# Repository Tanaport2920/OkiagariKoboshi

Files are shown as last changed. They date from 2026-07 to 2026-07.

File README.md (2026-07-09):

# Okiagari Koboshi Robot: Isaac Lab RL + M5Stack ATOM Matrix Deployment

2自由度サーボを持つ起き上がり小法師型ロボットを、Isaac Lab上でシミュレーション・強化学習し、最終的にM5Stack ATOM Matrixへ制御ポリシーを組み込むための開発メモです。

Real

Simulation

---

## 1. 目的

本プロジェクトの目的は、2軸サーボロボットを倒れた姿勢から自律的に起き上がらせることです。

開発方針は以下です。

```text
1. CAD / URDF / USD でロボットモデルを作成
2. Isaac Labで物理シミュレーション
3. 手動reference軌道で起き上がり動作を作成
4. referenceを教師軌道としてpolicyを学習
5. 学習済みActorをM5Stack ATOM Matrixへ組み込み
6. STS3032サーボを実機制御
```

---

## 3. 使用環境

### 3.1 シミュレーション環境

```text
OS:
  Ubuntu 24.04

GPU:
  NVIDIA GPU

NVIDIA Driver:
  Isaac Sim / Isaac Labに対応したNVIDIA Driver

Isaac Sim:
  Isaac Sim 5.1.0

Isaac Lab:
  Isaac Lab 2.3系

作業ディレクトリ:
  /workspace/isaaclab
  /workspace/OkiagariKoboshi_ws
```

### 3.2 実機環境

```text
Controller:
  M5Stack ATOM Matrix

MCU:
  ESP32-PICO-D4

IMU:
  MPU6886

Servo:
  FEETECH STS3032 x2

Development:
  PlatformIO
  Arduino framework
```

---

## 4. ディレクトリ構成

推奨構成は以下です。

```text
/workspace/OkiagariKoboshi_ws/
  assets/
    usd/
      okiagarikoboshi.usd
    urdf/
      okiagarikoboshi.urdf
    meshes/

  source/
    okiagari_koboshi_ext/
      pyproject.toml
      okiagari_koboshi_ext/
        __init__.py
        tasks/
          __init__.py
          direct/
            __init__.py
            okiagari_getup/
              __init__.py
              okiagari_getup_env.py
              agents/
                __init__.py
                rsl_rl_ppo_cfg.py
              references/
                __init__.py
                getup_reference.py

  tools/
    export_policy_to_c.py
```

---

## 5. Isaac Lab環境構築

Docker Composeを使う場合、ホスト側の作業ディレクトリは環境変数で渡します。

```bash
cd /path/to/OkiagariKoboshi_ws

OKIAGARI_WS_HOST=/path/to/OkiagariKoboshi_ws \
docker compose -f docker/compose.isaaclab.yml up
```

### 5.1 Isaac Labディレクトリへ移動

Isaac Labの実行は基本的に以下のディレクトリで行います。

```bash
cd /workspace/isaaclab
```

`isaaclab.sh` は `/workspace/isaaclab` にあります。
`/workspace/OkiagariKoboshi_ws` で以下を実行すると失敗します。

```bash
./isaaclab.sh
```

その場合は、必ず以下のように実行します。

```bash
cd /workspace/isaaclab
./isaaclab.sh ...
```

または絶対パスを使います。

```bash
/workspace/isaaclab/isaaclab.sh ...
```

---

## 6. Isaac Lab拡張パッケージのインストール

自作環境 `okiagari_koboshi_ext` をeditable installします。

```bash
cd /workspace/isaaclab

./isaaclab.sh -p -m pip install -e /workspace/OkiagariKoboshi_ws/source/okiagari_koboshi_ext
```

正常に入ると以下のようになります。

```text
Successfully installed okiagari-koboshi-ext-0.1.0
```

コードを変更した後は、念のため再度実行します。

```bash
cd /workspace/isaaclab

./isaaclab.sh -p -m pip install -e /workspace/OkiagariKoboshi_ws/source/okiagari_koboshi_ext
```

---

## 7. URDF / USD

ロボットのUSDファイルは以下を使用します。

```text
/workspace/OkiagariKoboshi_ws/assets/usd/okiagarikoboshi.usd
```

環境コード内では以下のように指定します。

```python
OKIAGARI_USD = "/workspace/OkiagariKoboshi_ws/assets/usd/okiagarikoboshi.usd"
```

関節名は以下です。

```text
revolute1
revolute2
```

body名は以下です。

```text
root
sts3032_horn_1
sts3032_horn
```

---

## 8. WebRTC表示

### 8.1 ロボット表示確認

WebRTCでIsaac Sim画面を表示する場合は以下を使います。

```bash
cd /workspace/isaaclab

PUBLIC_IP=YOUR_PUBLIC_IP \
LIVESTREAM=2 \
ENABLE_CAMERAS=1 \
./isaaclab.sh -p /workspace/OkiagariKoboshi_ws/isaac/scripts/spawn_robot.py \
  --kit_args "--/app/livestream/publicEndpointAddress=YOUR_PUBLIC_IP --/app/livestream/port=49100"
```

WebRTC Client側では以下へ接続します。

```text
YOUR_PUBLIC_IP
```

---

## 9. 学習中にGUIを映す

学習中にGUIを表示する場合は、`--headless` を付けません。

確認用は `num_envs` を少なくします。

```bash
cd /workspace/isaaclab

PUBLIC_IP=YOUR_PUBLIC_IP \
LIVESTREAM=2 \
ENABLE_CAMERAS=1 \
./isaaclab.sh -p scripts/reinforcement_learning/rsl_rl/train.py \
  --task OkiagariKoboshi-Getup-Direct-v0 \
  --num_envs 16 \
  --max_iterations 500 \
  --kit_args "--/app/livestream/publicEndpointAddress=YOUR_PUBLIC_IP --/app/livestream/port=49100"
```

本学習はheadless推奨です。

```bash
cd /workspace/isaaclab

./isaaclab.sh -p scripts/reinforcement_learning/rsl_rl/train.py \
  --task OkiagariKoboshi-Getup-Direct-v0 \
  --num_envs 512 \
  --headless \
  --max_iterations 1500
```

---

## 10. play.pyでの再生

RSL-RLの `play.py` では `--use_last_checkpoint` は使いません。
`--checkpoint` を指定します。

```bash
cd /workspace/isaaclab

CKPT=$(find logs/rsl_rl/okiagari_getup_v2 -type f -name "model_*.pt" | sort -V | tail -n 1)

PUBLIC_IP=YOUR_PUBLIC_IP \
LIVESTREAM=2 \
ENABLE_CAMERAS=1 \
./isaaclab.sh -p scripts/reinforcement_learning/rsl_rl/play.py \
  --task OkiagariKoboshi-Getup-Direct-v0 \
  --num_envs 16 \
  --checkpoint "$CKPT" \
  --kit_args "--/app/livestream/publicEndpointAddress=YOUR_PUBLIC_IP --/app/livestream/port=49100"
```

---

## 11. 観測設計

実機で取得できる量に合わせます。

```text
obs[0]  = sin(roll)
obs[1]  = cos(roll)
obs[2]  = sin(pitch)
obs[3]  = cos(pitch)

obs[4]  = gyro_x * 0.25
obs[5]  = gyro_y * 0.25

obs[6]  = q1 / q1_limit
obs[7]  = q2 / q2_limit

obs[8]  = dq1 * 0.10
obs[9]  = dq2 * 0.10

obs[10] = target1 / q1_limit
obs[11] = target2 / q2_limit
```

M5側でも同じ順番で `obs[12]` を作成します。

---

## 12. action設計

最初はpolicyが関節の絶対角度を出力する設計で試しましたが、最終的には参考記事に合わせて **差分action方式** にします。

```text
action[0] = revolute1 targetの増減
action[1] = revolute2 targetの増減
```

シミュレーション側・実機側で共通して以下のように扱います。

```cpp
target1 += action[0] * 0.08f;
target2 += action[1] * 0.08f;

target1 = constrain(target1, -1.57f, 1.57f);
target2 = constrain(target2, -2.09f, 2.09f);
```

---

## 13. PPO設定

`rsl_rl_ppo_cfg.py` の基本設定です。

```python
from isaaclab.utils import configclass
from isaaclab_rl.rsl_rl import (
    RslRlOnPolicyRunnerCfg,
    RslRlPpoActorCriticCfg,
    RslRlPpoAlgorithmCfg,
)

@configclass
class OkiagariGetupPPORunnerCfg(RslRlOnPolicyRunnerCfg):
    num_steps_per_env = 32
    max_iterations = 1500
    save_interval = 50
    experiment_name = "okiagari_getup_v2"
    empirical_normalization = False

    policy = RslRlPpoActorCriticCfg(
        init_noise_std=1.0,
        actor_hidden_dims=[64, 64],
        critic_hidden_dims=[64, 64],
        activation="relu",
    )

    algorithm = RslRlPpoAlgorithmCfg(
        value_loss_coef=1.0,
        use_clipped_value_loss=True,
        clip_param=0.2,
        entropy_coef=0.01,
        num_learning_epochs=5,
        num_mini_batches=4,
        learning_rate=3.0e-4,
        schedule="adaptive",
        gamma=0.99,
        lam=0.95,
        desired_kl=0.01,
        max_grad_norm=1.0,
    )
```

---

## 14. Ground摩擦設定

起き上がりでは床との摩擦が重要です。
地面摩擦は高めに設定します。

```python
def _setup_scene(self):
    self.robot = Articulation(self.cfg.robot_cfg)

    ground_cfg = GroundPlaneCfg(
        physics_material=sim_utils.RigidBodyMaterialCfg(
            static_friction=3.0,
            dynamic_friction=2.5,
            restitution=0.0,
            friction_combine_mode="max",
            restitution_combine_mode="min",
        )
    )
    spawn_ground_plane(prim_path="/World/ground", cfg=ground_cfg)

    self.scene.clone_environments(copy_from_source=False)
    if self.device == "cpu":
        self.scene.filter_collisions(global_prim_paths=[])
    self.scene.articulations["robot"] = self.robot

    light_cfg = sim_utils.DomeLightCfg(intensity=3000.0, color=(0.9, 0.9, 0.9))
    light_cfg.func("/World/Light", light_cfg)
```

---

## 15. Reference軌道

PPOでゼロから起き上がりを探索させると難しいため、まずは手動referenceを作成します。

形式は以下です。

```python
(時刻[s], revolute1目標角[rad], revolute2目標角[rad])
```

`getup_reference.py` の例です。

```python
GETUP_REFERENCE = {
    "roll_pos": [
        (0.00,  0.00,  0.00),
        (0.40,  0.50,  0.00),
        (0.90,  1.00,  0.00),
        (1.40,  1.57,  0.00),
        (2.00,  0.00,  0.00),
    ],

    "roll_neg": [
        (0.00,  0.00,  0.00),
        (0.40, -0.50,  0.00),
        (0.90, -1.00,  0.00),
        (1.40, -1.57,  0.00),
        (2.00,  0.00,  0.00),
    ],

    "pitch_pos": [
        (0.00,  0.00,  0.00),
        (0.40,  0.00,  0.70),
        (0.90,  0.00,  1.40),
        (1.40,  0.00,  2.09),
        (2.00,  0.00,  0.00),
    ],

    "pitch_neg": [
        (0.00,  0.00,  0.00),
        (0.40,  0.00, -0.70),
        (0.90,  0.00, -1.40),
        (1.40,  0.00, -2.09),
        (2.00,  0.00,  0.00),
    ],
}
```

現在、以下は起き上がり成功済みです。

```text
roll_pos
roll_neg
pitch_pos
pitch_neg
```

---

## 16. referenceの読み込み

`okiagari_getup_env.py` の先頭に追加します。

```python
from .references.getup_reference import GETUP_REFERENCE
```

configには以下を追加します。

```python
scripted_getup_mode = "roll_pos"
use_scripted_control = True
```

---

## 17. reference target計算

4姿勢のreferenceを自動で選ぶため、以下の関数を用意します。

```python
def _get_reference_target(self):
    t = self.episode_length_buf.float() * self.cfg.sim.dt * self.cfg.decimation
    target = torch.zeros(self.num_envs, 2, device=self.device)

    mode_names = ["roll_pos", "roll_neg", "pitch_pos", "pitch_neg"]

    for mode_id, mode_name in enumerate(mode_names):
        env_mask = self._mode_ids == mode_id
        if not torch.any(env_mask):
            continue

        ref = GETUP_REFERENCE[mode_name]

        for i in range(len(ref) - 1):
            t0, q10, q20 = ref[i]
            t1, q11, q21 = ref[i + 1]

            time_mask = (t >= t0) & (t < t1)
            mask = env_mask & time_mask

            alpha = torch.clamp((t - t0) / (t1 - t0), 0.0, 1.0)

            q1 = q10 + (q11 - q10) * alpha
            q2 = q20 + (q21 - q20) * alpha

            target[:, 0] = torch.where(mask, q1, target[:, 0])
            target[:, 1] = torch.where(mask, q2, target[:, 1])

        t_last, q1_last, q2_last = ref[-1]
        mask = env_mask & (t >= t_last)
        target[:, 0] = torch.where(mask, torch.full_like(t, q1_last), target[:, 0])
        target[:, 1] = torch.where(mask, torch.full_like(t, q2_last), target[:, 1])

    return target
```

---

## 18. scripted制御用_apply_action

reference再生確認時は、policy actionを無視してreferenceを流します。

```python
def _apply_action(self):
    self._ensure_action_buffers()

    if self.cfg.use_scripted_control:
        self._servo_targets.copy_(self._get_reference_target())
    else:
        self._servo_targets[:, 0] += self._actions[:, 0] * 0.08
        self._servo_targets[:, 1] += self._actions[:, 1] * 0.08

        self._servo_targets[:, 0] = torch.clamp(self._servo_targets[:, 0], -1.57, 1.57)
        self._servo_targets[:, 1] = torch.clamp(self._servo_targets[:, 1], -2.09, 2.09)

    self.robot.set_joint_position_target(
        self._servo_targets,
        joint_ids=self._joint_ids,
    )
```

---

## 19. action buffer初期化

以下を環境クラス内に用意します。

```python
def _ensure_action_buffers(self):
    if not hasattr(self, "_actions"):
        self._actions = torch.zeros(self.num_envs, 2, device=self.device)

    if not hasattr(self, "_previous_actions"):
        self._previous_actions = torch.zeros(self.num_envs, 2, device=self.device)

    if not hasattr(self, "_servo_targets"):
        self._servo_targets = torch.zeros(self.num_envs, 2, device=self.device)
```

reset時も初期化します。

```python
self._ensure_action_buffers()
self._actions[env_ids] = 0.0
self._previous_actions[env_ids] = 0.0
self._servo_targets[env_ids] = 0.0
```

---

## 20. reference追従報酬

policyにreferenceを真似させるため、報酬にreference追従項を追加します。

```python
ref_target = self._get_reference_target()
joint_pos_now = self.robot.data.joint_pos[:, self._joint_ids]

ref_error = torch.sum((joint_pos_now - ref_target) ** 2, dim=1)
ref_reward = 8.0 * torch.exp(-3.0 * ref_error)
```

rewardに追加します。

```python
reward = (
    ref_reward
    + height_reward
    + upright_reward
    + success_reward
    + ang_vel_penalty
    + joint_vel_penalty
    + action_penalty
    + action_rate_penalty
)
```

---

## 21. 学習の流れ

### 21.1 reference再生確認

```bash
cd /workspace/isaaclab

PUBLIC_IP=YOUR_PUBLIC_IP \
LIVESTREAM=2 \
ENABLE_CAMERAS=1 \
./isaaclab.sh -p scripts/reinforcement_learning/rsl_rl/train.py \
  --task OkiagariKoboshi-Getup-Direct-v0 \
  --num_envs 4 \
  --max_iterations 50 \
  --kit_args "--/app/livestream/publicEndpointAddress=YOUR_PUBLIC_IP --/app/livestream/port=49100"
```

この段階では `use_scripted_control = True` とします。

### 21.2 PPO学習

reference自動選択が確認できたら、以下にします。

```python
use_scripted_control = False
```

その後、headlessで学習します。

```bash
cd /workspace/isaaclab

./isaaclab.sh -p scripts/reinforcement_learning/rsl_rl/train.py \
  --task OkiagariKoboshi-Getup-Direct-v0 \
  --num_envs 512 \
  --headless \
  --max_iterations 1500
```

---

## 22. デバッグメモ

### 22.1 モータが回らない

サイン波を直接 `_apply_action()` で流して確認しました。
サイン波で関節が動いたため、以下は正常と判断しました。

```text
joint_ids
actuator設定
USD joint drive
set_joint_position_target()
```

問題はpolicyと報酬設計側でした。

### 22.2 upright判定

横で寝ている姿勢でも以下のように `z_z` が高く出ました。

```text
x_z ≈ 0
y_z ≈ 0.626
z_z ≈ 0.780
height ≈ 0.025
```

そのため、`upright` 単独ではなく `height` で報酬をゲートするようにしました。

### 22.3 getup_reference.pyが反映されない

`getup_reference.py` を作っても、`okiagari_getup_env.py` がimportしていなければ反映されません。

```python
from .references.getup_reference import GETUP_REFERENCE
```

を追加します。

### 22.4 scripted_getup_modeがない

以下のエラーが出た場合、

```text
AttributeError: 'OkiagariGetupEnvCfg' object has no attribute 'scripted_getup_mode'
```

configに追加します。

```python
scripted_getup_mode = "roll_pos"
```

### 22.5 _servo_targetsがない

以下のエラーが出た場合、

```text
AttributeError: 'OkiagariGetupEnv' object has no attribute '_servo_targets'
```

`_ensure_action_buffers()` に `_servo_targets` の初期化を追加します。

---

## 23. M5Stack ATOM Matrix側の環境構築

### 23.1 PlatformIO設定

`platformio.ini` は以下です。

```ini
[env:m5stack-atom]
platform = espressif32
board = m5stack-atom
framework = arduino

monitor_speed = 115200
upload_speed = 1500000

build_flags =
    -DCORE_DEBUG_LEVEL=1

lib_deps =
    m5stack/M5Atom
    fastled/FastLED
    ftservo/FTServo
```

---

## 24. M5側の推奨構成

```text
OkiagariM5/
  platformio.ini
  src/
    main.cpp
    imu_estimator.h
    imu_estimator.cpp
    servo_bus.h
    servo_bus.cpp
    reference_getup.h
    policy.h
    policy.cpp
    policy_weights.h
    config.h
```

役割：

```text
main.cpp:
  50Hz制御ループ、状態遷移、ボタン処理

imu_estimator:
  roll, pitch, gyro_x, gyro_y取得

servo_bus:
  STS3032への目標角送信
  STS3032から現在角度・速度読み取り

reference_getup:
  手動reference軌道再生

policy:
  学習済みActor MLPのforward実装

policy_weights:
  checkpointからC配列化した重み

config:
  サーボID、角度制限、周期、ゲイン
```

---

## 25. ATOM MatrixとFEETECHサーボドライバの接続

ATOM MatrixのGroveポートを使用します。

```text
ATOM Matrix HY2.0-4P

Black : GND
Red   : 5V
Yellow: G26
White : G32
```

G26/G32をUART2として使います。

```text
G26 = TX
G32 = RX
```

配線：

```text
ATOM Matrix              FEETECHサーボドライバ基板
------------------------------------------------
GND / Black       -----> GND
G26 / Yellow      -----> RX
G32 / White       <----- TX
```

サーボ電源はATOMから取らないようにします。

```text
ATOM:
  USB 5V給電

STS3032:
  外部電源 5〜7.4V
  GNDはATOMと共通
```

UART初期化：

```cpp
HardwareSerial ServoSerial(2);

constexpr int SERVO_TX_PIN = 26;
constexpr int SERVO_RX_PIN = 32;
constexpr int SERVO_BAUD   = 1000000;

void setup() {
    Serial.begin(115200);
    ServoSerial.begin(SERVO_BAUD, SERIAL_8N1, SERVO_RX_PIN, SERVO_TX_PIN);
}
```

ESP32 Arduinoの `begin()` は以下の順です。

```cpp
begin(baud, config, rxPin, txPin)
```

したがって、今回の場合は以下です。

```cpp
ServoSerial.begin(1000000, SERIAL_8N1, 32, 26);
```

---

## 26. M5側の制御周期

Isaac Lab側のpolicy周期は50Hz想定です。
M5側も20ms周期で動かします。

```cpp
constexpr uint32_t POLICY_PERIOD_US = 20000;
```

基本ループ：

```cpp
void loop() {
    static uint32_t last_us = micros();
    uint32_t now = micros();

    if ((uint32_t)(now - last_us) < POLICY_PERIOD_US) {
        return;
    }
    last_us += POLICY_PERIOD_US;

    // 1. IMU取得
    // 2. サーボ状態取得
    // 3. obs作成
    // 4. policy推論
    // 5. target更新
    // 6. サーボへ送信
}
```

---

## 27. M5側reference再生

最初にpolicyを載せるのではなく、Isaac Labで成功したreference軌道をM5で再生します。

`reference_getup.h` の例です。

```cpp
#pragma once
#include <stdint.h>

enum GetupMode {
    ROLL_POS = 0,
    ROLL_NEG = 1,
    PITCH_POS = 2,
    PITCH_NEG = 3,
};

struct Waypoint {
    float t;
    float q1;
    float q2;
};

static const Waypoint REF_ROLL_POS[] = {
    {0.00f, 0.00f, 0.00f},
    {0.40f, 0.50f, 0.00f},
    {0.90f, 1.00f, 0.00f},
    {1.40f, 1.57f, 0.00f},
    {2.00f, 0.00f, 0.00f},
};

static const Waypoint REF_ROLL_NEG[] = {
    {0.00f, 0.00f, 0.00f},
    {0.40f, -0.50f, 0.00f},
    {0.90f, -1.00f, 0.00f},
    {1.40f, -1.57f, 0.00f},
    {2.00f, 0.00f, 0.00f},
};

static const Waypoint REF_PITCH_POS[] = {
    {0.00f, 0.00f, 0.00f},
    {0.40f, 0.00f, 0.70f},
    {0.90f, 0.00f, 1.40f},
    {1.40f, 0.00f, 2.09f},
    {2.00f, 0.00f, 0.00f},
};

static const Waypoint REF_PITCH_NEG[] = {
    {0.00f, 0.00f, 0.00f},
    {0.40f, 0.00f, -0.70f},
    {0.90f, 0.00f, -1.40f},
    {1.40f, 0.00f, -2.09f},
    {2.00f, 0.00f, 0.00f},
};

inline void interpolateReference(
    const Waypoint* ref,
    int n,
    float t,
    float& q1,
    float& q2
) {
    if (t <= ref[0].t) {
        q1 = ref[0].q1;
        q2 = ref[0].q2;
        return;
    }

    for (int i = 0; i < n - 1; i++) {
        if (t >= ref[i].t && t < ref[i + 1].t) {
            float a = (t - ref[i].t) / (ref[i + 1].t - ref[i].t);
            q1 = ref[i].q1 + (ref[i + 1].q1 - ref[i].q1) * a;
            q2 = ref[i].q2 + (ref[i + 1].q2 - ref[i].q2) * a;
            return;
        }
    }

    q1 = ref[n - 1].q1;
    q2 = ref[n - 1].q2;
}

inline void getReferenceTarget(GetupMode mode, float t, float& q1, float& q2) {
    switch (mode) {
        case ROLL_POS:
            interpolateReference(REF_ROLL_POS, sizeof(REF_ROLL_POS) / sizeof(Waypoint), t, q1, q2);
            break;
        case ROLL_NEG:
            interpolateReference(REF_ROLL_NEG, sizeof(REF_ROLL_NEG) / sizeof(Waypoint), t, q1, q2);
            break;
        case PITCH_POS:
            interpolateReference(REF_PITCH_POS, sizeof(REF_PITCH_POS) / sizeof(Waypoint), t, q1, q2);
            break;
        case PITCH_NEG:
            interpolateReference(REF_PITCH_NEG, sizeof(REF_PITCH_NEG) / sizeof(Waypoint), t, q1, q2);
            break;
    }
}
```

---

## 28. checkpointからM5用policyへ変換

M5にPyTorchを載せるのではなく、Actorの重みをC配列に変換します。

### 28.1 exportスクリプト

`/workspace/OkiagariKoboshi_ws/tools/export_policy_to_c.py` を作成します。

```python
import argparse
from pathlib import Path

import torch

def find_actor_layers(state_dict):
    candidates = []

    for k, v in state_dict.items():
        if not k.endswith(".weight"):
            continue
        if v.ndim != 2:
            continue
        if "critic" in k.lower():
            continue
        if "actor" not in k.lower():
            continue

        out_dim, in_dim = v.shape
        candidates.append((k, in_dim, out_dim))

    expected = [(12, 64), (64, 64), (64, 2)]
    layers = []

    for in_dim, out_dim in expected:
        matched = None
        for k, kin, kout in candidates:
            if kin == in_dim and kout == out_dim:
                matched = k
                break
        if matched is None:
            raise RuntimeError(f"Could not find actor layer {in_dim}->{out_dim}. candidates={candidates}")
        layers.append(matched)

    return layers

def array_to_c(name, tensor):
    flat = tensor.detach().cpu().float().contiguous().view(-1).numpy()
    values = ", ".join(f"{x:.9g}f" for x in flat)
    return f"static const float {name}[{len(flat)}] = {{\n    {values}\n}};\n"

def main():
    parser = argparse.ArgumentParser()
    parser.add_argument("--checkpoint", required=True)
    parser.add_argument("--out", required=True)
    args = parser.parse_args()

    ckpt = torch.load(args.checkpoint, map_location="cpu")

    if "model_state_dict" in ckpt:
        sd = ckpt["model_state_dict"]
    elif "state_dict" in ckpt:
        sd = ckpt["state_dict"]
    else:
        sd = ckpt

    w_keys = find_actor_layers(sd)
    b_keys = [k.replace(".weight", ".bias") for k in w_keys]

    for k in b_keys:
        if k not in sd:
            raise RuntimeError(f"Missing bias: {k}")

    out = []
    out.append("#pragma once\n")
    out.append("// Auto-generated from RSL-RL Actor checkpoint\n")
    out.append("#define POLICY_IN_DIM 12\n")
    out.append("#define POLICY_H1_DIM 64\n")
    out.append("#define POLICY_H2_DIM 64\n")
    out.append("#define POLICY_OUT_DIM 2\n\n")

    out.append(array_to_c("W1", sd[w_keys[0]]))
    out.append(array_to_c("B1", sd[b_keys[0]]))
    out.append(array_to_c("W2", sd[w_keys[1]]))
    out.append(array_to_c("B2", sd[b_keys[1]]))
    out.append(array_to_c("W3", sd[w_keys[2]]))
    out.append(array_to_c("B3", sd[b_keys[2]]))

    Path(args.out).write_text("\n".join(out))
    print(f"wrote: {args.out}")

if __name__ == "__main__":
    main()
```

### 28.2 実行

```bash
cd /workspace/isaaclab

CKPT=$(find logs/rsl_rl/okiagari_getup_v2 -type f -name "model_*.pt" | sort -V | tail -n 1)

./isaaclab.sh -p /workspace/OkiagariKoboshi_ws/tools/export_policy_to_c.py \
  --checkpoint "$CKPT" \
  --out /workspace/OkiagariKoboshi_ws/policy_weights.h
```

生成された `policy_weights.h` をPlatformIOプロジェクトにコピーします。

```text
src/policy_weights.h
```

---

## 29. M5側policy推論

`policy.h`

```cpp
#pragma once

void policyForward(const float obs[12], float action[2]);
```

`policy.cpp`

```cpp
#include "policy.h"
#include "policy_weights.h"
#include <math.h>

static inline float relu(float x) {
    return x > 0.0f ? x : 0.0f;
}

static void linear(
    const float* x,
    const float* W,
    const float* b,
    float* y,
    int in_dim,
    int out_dim
) {
    for (int o = 0; o < out_dim; o++) {
        float sum = b[o];
        for (int i = 0; i < in_dim; i++) {
            sum += W[o * in_dim + i] * x[i];
        }
        y[o] = sum;
    }
}

void policyForward(const float obs[12], float action[2]) {
    float h1[64];
    float h2[64];
    float out[2];

    linear(obs, W1, B1, h1, 12, 64);
    for (int i = 0; i < 64; i++) {
        h1[i] = relu(h1[i]);
    }

    linear(h1, W2, B2, h2, 64, 64);
    for (int i = 0; i < 64; i++) {
        h2[i] = relu(h2[i]);
    }

    linear(h2, W3, B3, out, 64, 2);

    action[0] = fmaxf(-1.0f, fminf(1.0f, out[0]));
    action[1] = fmaxf(-1.0f, fminf(1.0f, out[1]));
}
```

---

## 30. 実機側obs作成

```cpp
void buildObservation(
    float roll,
    float pitch,
    float gyro_x,
    float gyro_y,
    float q1,
    float q2,
    float dq1,
    float dq2,
    float target1,
    float target2,
    float obs[12]
) {
    obs[0]  = sinf(roll);
    obs[1]  = cosf(roll);
    obs[2]  = sinf(pitch);
    obs[3]  = cosf(pitch);

    obs[4]  = gyro_x * 0.25f;
    obs[5]  = gyro_y * 0.25f;

    obs[6]  = q1 / 1.57f;
    obs[7]  = q2 / 2.09f;

    obs[8]  = dq1 * 0.10f;
    obs[9]  = dq2 * 0.10f;

    obs[10] = target1 / 1.57f;
    obs[11] = target2 / 2.09f;
}
```

---

## 31. 実機投入時の安全制限

最初からpolicyを全力で使わないようにします。

```cpp
action[0] = clampf(action[0], -0.3f, 0.3f);
action[1] = clampf(action[1], -0.3f, 0.3f);
```

段階的に制限を緩めます。

```text
±0.3
↓
±0.5
↓
±0.8
↓
±1.0
```

---

## 32. 実機移植の確認順序

```text
1. ATOM MatrixでLED点灯
2. IMUからroll / pitch / gyro取得
3. STS3032 2個のID確認
4. STS3032へ目標角送信
5. STS3032から現在角度読み取り
6. M5からreference軌道再生
7. 実機で4姿勢から起き上がるか確認
8. policy_weights.hを組み込む
9. policyForwardの出力確認
10. action制限付きでpolicy制御
11. action制限を段階的に緩める
```

---

## 33. 重要方針

以下の順番を守ります。

```text
手動referenceでシミュレーションが立つ
↓
手動referenceで実機が立つ
↓
policyがシミュレーションで立つ
↓
policyをM5へ移植
↓
実機でaction制限付きpolicy確認
↓
制限を緩めて本番動作
```

いきなりpolicyを実機に載せるのではなく、まずM5上でreference再生を成功させます。
これにより、IMU軸、サーボ符号、角度スケール、通信周期のズレを先に潰せます。

---

## 34. よく使うコマンドまとめ

### 拡張パッケージ再インストール

```bash
cd /workspace/isaaclab

./isaaclab.sh -p -m pip install -e /workspace/OkiagariKoboshi_ws/source/okiagari_koboshi_ext
```

### GUIあり学習

```bash
cd /workspace/isaaclab

PUBLIC_IP=YOUR_PUBLIC_IP \
LIVESTREAM=2 \
ENABLE_CAMERAS=1 \
./isaaclab.sh -p scripts/reinforcement_learning/rsl_rl/train.py \
  --task OkiagariKoboshi-Getup-Direct-v0 \
  --num_envs 16 \
  --max_iterations 500 \
  --kit_args "--/app/livestream/publicEndpointAddress=YOUR_PUBLIC_IP --/app/livestream/port=49100"
```

### headless本学習

```bash
cd /workspace/isaaclab

./isaaclab.sh -p scripts/reinforcement_learning/rsl_rl/train.py \
  --task OkiagariKoboshi-Getup-Direct-v0 \
  --num_envs 512 \
  --headless \
  --max_iterations 1500
```

### play

```bash
cd /workspace/isaaclab

CKPT=$(find logs/rsl_rl/okiagari_getup_v2 -type f -name "model_*.pt" | sort -V | tail -n 1)

PUBLIC_IP=YOUR_PUBLIC_IP \
LIVESTREAM=2 \
ENABLE_CAMERAS=1 \
./isaaclab.sh -p scripts/reinforcement_learning/rsl_rl/play.py \
  --task OkiagariKoboshi-Getup-Direct-v0 \
  --num_envs 16 \
  --checkpoint "$CKPT" \
  --kit_args "--/app/livestream/publicEndpointAddress=YOUR_PUBLIC_IP --/app/livestream/port=49100"
```

### policy_weights.h生成

```bash
cd /workspace/isaaclab

CKPT=$(find logs/rsl_rl/okiagari_getup_v2 -type f -name "model_*.pt" | sort -V | tail -n 1)

./isaaclab.sh -p /workspace/OkiagariKoboshi_ws/tools/export_policy_to_c.py \
  --checkpoint "$CKPT" \
  --out /workspace/OkiagariKoboshi_ws/policy_weights.h
```

---

## 35. 現在の実装との差分・補足メモ

このREADMEには開発途中の古い方針も残っています。
現在の `okiagari_getup_env.py` / M5 firmware に合わせる場合は、この章の内容を優先します。

### 35.1 GUIで学習中ロボットが見えない場合

学習中にGUIは表示されていても、カメラが学習中のenvを見ていないことがあります。
512環境で学習すると、ロボットは `env_spacing=2.0` で広い範囲に並びます。

確認時はまずenv数を減らします。

```bash
cd /workspace/isaaclab

PUBLIC_IP=YOUR_PUBLIC_IP \
LIVESTREAM=2 \
ENABLE_CAMERAS=1 \
./isaaclab.sh -p scripts/reinforcement_learning/rsl_rl/train.py \
  --task OkiagariKoboshi-Getup-Direct-v0 \
  --num_envs 1 \
  --max_iterations 1000 \
  --kit_args "--/app/livestream/publicEndpointAddress=YOUR_PUBLIC_IP --/app/livestream/port=49100"
```

多数envで見る場合は、Stage上で以下を選んで `F` キーでフォーカスします。

```text
/World/envs/env_0/Robot
```

### 35.2 現在の観測は13次元

古い記述では12次元になっていますが、現在はphaseを追加して13次元です。

```text
obs[0]  = sin(roll)
obs[1]  = cos(roll)
obs[2]  = sin(pitch)
obs[3]  = cos(pitch)
obs[4]  = gyro_x * 0.25
obs[5]  = gyro_y * 0.25
obs[6]  = clamp(q1 / 1.20, -1.5, 1.5)
obs[7]  = clamp(q2 / 1.50, -1.5, 1.5)
obs[8]  = dq1 * 0.10
obs[9]  = dq2 * 0.10
obs[10] = current_servo_target1 / 1.57
obs[11] = current_servo_target2 / 2.09
obs[12] = episode_phase
```

M5側も `OkiagariPolicy::kObservationSize = 13` です。
12次元で学習したcheckpointは、13次元環境にはそのまま読み込めません。

```text
size mismatch for actor.0.weight:
copying a param with shape torch.Size([64, 12])
the shape in current model is torch.Size([64, 13])
```

この場合は新しい13次元設定で学習し直します。

### 35.3 現在のactionは差分ではなく絶対サーボ目標

古い方針では差分actionでしたが、現在のpolicy actionは絶対目標角です。

```text
action[0] in [-1, 1] -> revolute1 target = action[0] * 1.57 rad
action[1] in [-1, 1] -> revolute2 target = action[1] * 2.09 rad
```

その後、実サーボ仕様に合わせて目標値へ速度制限付きで近づけます。

```text
STS3032想定:
  60度 / 0.09秒

servo_speed_limit:
  1.0471976 rad / 0.09 s
```

Isaac Lab側は200Hz physicsなので、1 physics stepあたり約0.058 radまでしか目標を動かしません。
M5 firmware側も同じ考えで `moveTargetsToward()` により目標角を制限します。

### 35.4 落下してから制御を開始する

現在は、reset直後にpolicy/referenceが動き始めないようにしています。

```python
drop_settle_time_s = 0.35
```

この時間中は以下の動作になります。

```text
servo target        = [0, 0]
reference time      = 0
episode phase       = 0
upright/success報酬 = 無効
```

debug logでは以下で確認します。

```text
active=False  -> 落下・接地待ち
active=True   -> getup制御開始
```

### 35.5 reset姿勢とPOS/NEGの符号

reset時は4種類のreference basinをランダムに選びます。

```text
0: roll_pos
1: roll_neg
2: pitch_pos
3: pitch_neg
```

現在のreset符号は、手動referenceで成功確認した向きに合わせています。

```python
roll[mode_ids == 0] = -0.5 * math.pi  # roll_pos
roll[mode_ids == 1] =  0.5 * math.pi  # roll_neg
pitch[mode_ids == 2] = -0.5 * math.pi # pitch_pos
pitch[mode_ids == 3] =  0.5 * math.pi # pitch_neg
```

さらに、実機での落下ばらつきを想定して高さ、roll、pitch、yaw、初期関節角をランダム化しています。

### 35.6 success判定は直立だけではなく関節ニュートラルも見る

一時期、以下のようなログが出ていました。

```text
z_z=0.962
success=True
joint_pos=[-1.567, -0.040]
```

これは「本体は立っているが、1軸目が限界まで曲がったまま」でも成功になっていた状態です。
現在は、直立だけではsuccessにしません。

現在のsuccess条件は概念的には以下です。

```text
upright_score > 0.95
and joint_pos がニュートラル近傍
and desired target がニュートラル近傍
and active=True
```

debug logには以下も出します。

```text
stand_joint_err
stand_cmd_err
```

ここが大きい場合は「立っているがモータが伸びていない」状態です。

### 35.7 報酬設計の現在の注意点

root heightはsuccess判定に使いません。
このUSDでは、見た目上の直立時でもroot heightが低く出ることがあるためです。

主に使う信号は以下です。

```text
body local Z axisのworld Z成分:
  z_z ≈ 1.0 -> 直立
  z_z ≈ 0.0 -> 横倒し
```

`height_score` はdebug用に残していますが、success判定には使いません。

reference追従報酬は、ゼロ姿勢に止まるだけで得をしないように、現在は「完全一致で0、外れると負」の形にしています。

```text
reference_reward <= 0
command_reference_reward <= 0
```

### 35.8 checkpoint / play.pyの注意

観測次元、ネットワーク構造、action設計を変えた後は、古いcheckpointをそのまま使えません。

特に以下を変更したら新規学習を推奨します。

```text
observation_space
actionの意味
報酬設計
success条件
reference時刻
drop_settle_time_s
```

`play.py` では `--checkpoint` を明示します。

```bash
cd /workspace/isaaclab

CKPT=$(find logs/rsl_rl/okiagari_getup_v2 -type f -name "model_*.pt" | sort -V | tail -n 1)

PUBLIC_IP=YOUR_PUBLIC_IP \
LIVESTREAM=2 \
ENABLE_CAMERAS=1 \
./isaaclab.sh -p scripts/reinforcement_learning/rsl_rl/play.py \
  --task OkiagariKoboshi-Getup-Direct-v0 \
  --num_envs 1 \
  --checkpoint "$CKPT" \
  --kit_args "--/app/livestream/publicEndpointAddress=YOUR_PUBLIC_IP --/app/livestream/port=49100"
```

### 35.9 現在のpolicy export

`tools/export_policy_to_c.py` は現在、デフォルトで13次元入力を出力します。

```bash
cd /workspace/isaaclab

CKPT=$(find logs/rsl_rl/okiagari_getup_v2 -type f -name "model_*.pt" | sort -V | tail -n 1)

./isaaclab.sh -p /workspace/OkiagariKoboshi_ws/tools/export_policy_to_c.py \
  --checkpoint "$CKPT" \
  --out /workspace/OkiagariKoboshi_ws/firmware/M5AtomMATRIX_Okiagari/src/policy_weights.h
```

明示する場合は以下です。

```bash
./isaaclab.sh -p /workspace/OkiagariKoboshi_ws/tools/export_policy_to_c.py \
  --checkpoint "$CKPT" \
  --out /workspace/OkiagariKoboshi_ws/firmware/M5AtomMATRIX_Okiagari/src/policy_weights.h \
  --input-dim 13 \
  --h1-dim 64 \
  --h2-dim 64 \
  --output-dim 2
```

M5側は起動時に以下のようなログを出します。

```text
[policy] weights found input=13 h1=64 h2=64 output=2 firmware_obs=13
```

次元が合わない場合は、policy出力を使わずゼロactionへ戻します。

### 35.10 M5 firmware側の現在の対応

M5側も現在のIsaac Lab環境に合わせています。

```text
policy周期:
  50Hz

episode length:
  4.0s

drop settle:
  0.35s

policy action:
  normalized absolute servo target

servo target:
  speed limited
```

`main.cpp` では、policy/referenceともに `kDropSettleTimeS` 経過までは目標角をゼロに保ちます。

```text
elapsed < kDropSettleTimeS:
  desiredRad = [0, 0]

elapsed >= kDropSettleTimeS:
  reference or policy targetを使用
```

実機投入時は、まずReference modeで4姿勢を確認してからPolicy modeへ進みます。

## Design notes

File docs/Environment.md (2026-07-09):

# OkiagariKoboshi_ws 環境構築メモ

## 目的

2軸サーボで倒れた状態から起き上がるロボットを、Isaac Sim / Isaac Lab を用いた強化学習で開発する。

全体構成は以下の通り。

```text
PC / GPUサーバ
  Ubuntu 22.04 or 24.04
  NVIDIA Driver
  Docker
  NVIDIA Container Toolkit
  Isaac Sim + Isaac Lab
        ↓
  強化学習 PPO
        ↓
  学習済みpolicyを軽量化
        ↓
M5Stack Core2
  IMUでroll/pitch推定
  policy推論
  2軸サーボへ目標角送信
```

---

## 基本方針

`OkiagariKoboshi_ws` をGitHubで管理する。

ただし、GitHubに入れるのは **Dockerコンテナ本体ではなく、コンテナを再現するための設定ファイル** とする。

GitHubに入れるもの：

```text
Dockerfile
docker-compose.yml
Pythonコード
Isaac Labのtask定義
CADデータ
URDF / USD / mesh
M5Stack Core2のfirmware
policy export用スクリプト
小さい学習済みpolicy
```

GitHubに入れないもの：

```text
Docker image本体
Docker container本体
*.tar のDocker image
Isaac Simのcache
大量の学習ログ
巨大checkpoint
```

---

## 推奨ディレクトリ構成

```text
OkiagariKoboshi_ws/
├── README.md
├── .gitignore
├── .gitattributes
│
├── docker/
│   ├── compose.isaaclab.yml
│   ├── Dockerfile.dev
│   └── .env.example
│
├── cad/
│   ├── original/
│   ├── export_step/
│   ├── export_stl/
│   └── export_urdf/
│
├── assets/
│   ├── urdf/
│   ├── usd/
│   ├── meshes/
│   └── textures/
│
├── isaac/
│   ├── tasks/
│   │   └── okiagari_koboshi/
│   ├── robots/
│   ├── scripts/
│   │   ├── train.py
│   │   ├── play.py
│   │   └── export_policy.py
│   └── configs/
│
├── firmware/
│   └── m5stack_core2/
│       ├── platformio.ini
│       └── src/
│           └── main.cpp
│
├── policies/
│   ├── exported/
│   └── README.md
│
└── docs/
    ├── setup_windows.md
    ├── setup_server.md
    └── sim2real_notes.md
```

---

## Windows側の前提

Windowsでは以下を使う。

```text
Windows
  Docker Desktop
  WSL2
  Ubuntu-24.04 WSL
  VS Code
```

最初にPowerShellでWSLの状態を確認した。

```powershell
wsl -l -v
```

表示が以下のようになっていた。

```text
NAME              STATE           VERSION
docker-desktop    Running         2
```

この状態では、通常作業用のUbuntu WSLがまだ入っていない。
`docker-desktop` はDocker Desktop内部用のWSL環境であり、開発作業に使う場所ではない。

---

## Ubuntu 24.04 WSLの追加

PowerShellで実行する。

```powershell
wsl --install -d Ubuntu-24.04
```

インストール後、確認する。

```powershell
wsl -l -v
```

理想的には以下のようになる。

```text
NAME              STATE           VERSION
Ubuntu-24.04      Running         2
docker-desktop    Running         2
```

Ubuntuに入る。

```powershell
wsl -d Ubuntu-24.04
```

---

## Docker Desktop側の設定

Docker Desktopを開き、Ubuntu WSLとの連携をONにする。

```text
Docker Desktop
  Settings
    Resources
      WSL Integration
        Ubuntu-24.04 をON
```

その後、Ubuntu WSL側でDockerが使えるか確認する。

```bash
docker version
docker ps
```

`docker ps` が通れば、WSLからDocker Desktopを操作できている。

---

## Windows側にあるワークスペースをWSL側へ移動

もともとのプロジェクトはWindows側にある。

```text
C:\Users\hanaj\OkiagariKoboshi_ws
```

WSLからは以下のように見える。

```bash
/mnt/c/Users/hanaj/OkiagariKoboshi_ws
```

ただし、Docker / Isaac Labの開発では、WSLのLinuxファイルシステム側に置く方が安全。

Ubuntu WSLで以下を実行する。

```bash
cd ~
cp -r /mnt/c/Users/hanaj/OkiagariKoboshi_ws ~/OkiagariKoboshi_ws
cd ~/OkiagariKoboshi_ws
```

確認する。

```bash
pwd
ls
```

以下のような場所になっていればよい。

```text
/home/<ユーザー名>/OkiagariKoboshi_ws
```

---

## WindowsエクスプローラからWSL側を見る方法

Windowsのエクスプローラで以下を開く。

```text
\\wsl$\Ubuntu-24.04\home\<ユーザー名>\OkiagariKoboshi_ws
```

以後は、基本的にこのWSL側の `OkiagariKoboshi_ws` を開発対象にする。

---

## VS Codeで開く場所

VS Codeは **コンテナの中ではなく、Ubuntu WSL側で開く**。

正しい流れ：

```bash
cd ~/OkiagariKoboshi_ws
code .
```

VS Code左下に以下のように表示されていればOK。

```text
WSL: Ubuntu-24.04
```

---

## `code .` が使えない場合

コンテナ内で以下を実行しても失敗する。

```bash
code .
```

エラー例：

```text
bash: code: command not found
```

これは正常。
今いる場所がDockerコンテナ内だからである。

例：

```text
root@docker-desktop:/workspace/OkiagariKoboshi_ws#
```

この状態ではVS Codeを起動する場所ではない。

一度コンテナから出る。

```bash
exit
```

その後、Ubuntu WSL側で実行する。

```bash
cd ~/OkiagariKoboshi_ws
code .
```

---

## Docker composeファイル

`docker/compose.isaaclab.yml` を作成する。

```yaml
services:
  isaaclab:
    image: nvcr.io/nvidia/isaac-lab:2.3.2
    container_name: okiagari_isaaclab
    gpus: all
    stdin_open: true
    tty: true

    environment:
      - ACCEPT_EULA=Y
      - PRIVACY_CONSENT=Y
      - NVIDIA_VISIBLE_DEVICES=all
      - NVIDIA_DRIVER_CAPABILITIES=all

    volumes:
      - /home/<ユーザー名>/OkiagariKoboshi_ws:/workspace/OkiagariKoboshi_ws:rw
      - /home/<ユーザー名>/OkiagariKoboshi_ws/docker/isaac-cache/kit:/isaac-sim/kit/cache:rw
      - /home/<ユーザー名>/OkiagariKoboshi_ws/docker/isaac-cache/ov:/root/.cache/ov:rw
      - /home/<ユーザー名>/OkiagariKoboshi_ws/docker/isaac-cache/pip:/root/.cache/pip:rw
      - /home/<ユーザー名>/OkiagariKoboshi_ws/docker/isaac-cache/glcache:/root/.cache/nvidia/GLCache:rw
      - /home/<ユーザー名>/OkiagariKoboshi_ws/docker/isaac-cache/computecache:/root/.nv/ComputeCache:rw

    working_dir: /workspace/OkiagariKoboshi_ws

    entrypoint: /bin/bash
    command: -lc "sleep infinity"
```

`/home/<ユーザー名>/OkiagariKoboshi_ws` は、実際の `pwd` の結果に合わせて変更する。

確認方法：

```bash
cd ~/OkiagariKoboshi_ws
pwd
```

例：

```text
/home/hanaj/OkiagariKoboshi_ws
```

その場合は、compose内のパスも以下のようにする。

```yaml
- /home/hanaj/OkiagariKoboshi_ws:/workspace/OkiagariKoboshi_ws:rw
```

---

## 相対パスではなく絶対パスを使う理由

最初は以下のようにしていた。

```yaml
volumes:
  - ..:/workspace/OkiagariKoboshi_ws:rw
```

しかし、この場合、`docker compose` をどの場所から実行したかによって `..` の解釈がずれる可能性がある。

その結果、コンテナ内で作ったファイルがWSL側で見えないことがある。

そのため、確実にするために絶対パスを使う。

```yaml
volumes:
  - /home/<ユーザー名>/OkiagariKoboshi_ws:/workspace/OkiagariKoboshi_ws:rw
```

---

## Isaac Labコンテナの起動

Ubuntu WSL側で実行する。

```bash
cd ~/OkiagariKoboshi_ws
docker compose --project-directory . -f docker/compose.isaaclab.yml pull
```

起動する。

```bash
docker compose --project-directory . -f docker/compose.isaaclab.yml up -d
```

起動確認。

```bash
docker ps
```

`okiagari_isaaclab` が表示されればOK。

---

## コンテナに入る

Ubuntu WSL側で実行する。

```bash
cd ~/OkiagariKoboshi_ws
docker compose --project-directory . -f docker/compose.isaaclab.yml exec isaaclab bash
```

コンテナ内で確認する。

```bash
pwd
ls
```

以下の場所にいればOK。

```text
/workspace/OkiagariKoboshi_ws
```

---

## WSL側とコンテナ側の対応関係

重要な対応関係は以下。

```text
WSL側:
~/OkiagariKoboshi_ws

コンテナ側:
/workspace/OkiagariKoboshi_ws
```

この2つは同じ中身であるべき。

VS Codeで編集する場所：

```text
~/OkiagariKoboshi_ws
```

Isaac Labコンテナ内で実行する場所：

```text
/workspace/OkiagariKoboshi_ws
```

---

## マウント確認テスト

コンテナ内で以下を実行する。

```bash
cd /workspace/OkiagariKoboshi_ws
touch test_from_container.txt
mkdir -p isaac/scripts
touch isaac/scripts/test.txt
```

コンテナから出る。

```bash
exit
```

WSL側で確認する。

```bash
cd ~/OkiagariKoboshi_ws
ls
ls isaac/scripts
```

以下が見えれば成功。

```text
test_from_container.txt
test.txt
```

---

## コンテナ内で作ったフォルダがWSL側に見えない場合

原因はほぼ以下。

```text
コンテナ内の /workspace/OkiagariKoboshi_ws
と
WSL側の ~/OkiagariKoboshi_ws
が同じ場所にマウントされていない
```

対策：

1. `docker/compose.isaaclab.yml` の `volumes:` を絶対パスにする
2. 既存コンテナを作り直す

作り直しコマンド：

```bash
cd ~/OkiagariKoboshi_ws

docker compose --project-directory . -f docker/compose.isaaclab.yml down
docker compose --project-directory . -f docker/compose.isaaclab.yml up -d --force-recreate
```

入り直す。

```bash
docker compose --project-directory . -f docker/compose.isaaclab.yml exec isaaclab bash
```

---

## Isaac Labの存在確認

コンテナ内で実行する。

```bash
ls /workspace
ls /workspace/IsaacLab
```

Isaac LabのPython環境確認。

```bash
cd /workspace/IsaacLab
./isaaclab.sh -p -c "import torch; print(torch.__version__); print(torch.cuda.is_available())"
```

`True` が出れば、PyTorchからGPUが見えている。

---

## 自作スクリプトの実行テスト

コンテナ内で作成する。

```bash
cd /workspace/OkiagariKoboshi_ws
mkdir -p isaac/scripts
nano isaac/scripts/check_env.py
```

中身：

```python
import torch

print("Torch:", torch.__version__)
print("CUDA available:", torch.cuda.is_available())

if torch.cuda.is_available():
    print("GPU:", torch.cuda.get_device_name(0))

print("OkiagariKoboshi workspace OK")
```

実行する。

```bash
cd /workspace/IsaacLab
./isaaclab.sh -p /workspace/OkiagariKoboshi_ws/isaac/scripts/check_env.py
```

これが通れば、自分のGit管理フォルダ内のPythonコードをIsaac Lab環境で実行できている。

---

## Git管理

WSL側でGit管理する。

```bash
cd ~/OkiagariKoboshi_ws
git status
git add .
git commit -m "Add Isaac Lab docker workspace"
```

GitHubリポジトリを作った後、remoteを設定する。

SSHの場合：

```bash
git remote add origin git@github.com:Tanaport2920/OkiagariKoboshi_ws.git
git branch -M main
git push -u origin main
```

HTTPSの場合：

```bash
git remote add origin https://github.com/Tanaport2920/OkiagariKoboshi_ws.git
git branch -M main
git push -u origin main
```

---

## `.gitignore` の例

```gitignore
# Python
__pycache__/
*.pyc
.venv/
venv/

# Docker / large images
*.tar
*.tar.gz
*.img

# Isaac Sim / Isaac Lab caches and logs
docker/isaac-cache/
logs/
runs/
wandb/
.cache/
*.log

# Training artifacts
checkpoints/
*.ckpt
*.pth
*.pt
*.onnx
*.engine

# Allow small exported policy files only if needed
!policies/exported/

# OS
.DS_Store
Thumbs.db

# VSCode
.vscode/
```

---

## CADファイル用 `.gitattributes`

CADやmeshは大きくなりやすいため、Git LFSを使うのが望ましい。

`.gitattributes` の例：

```gitattributes
*.step filter=lfs diff=lfs merge=lfs -text
*.stp  filter=lfs diff=lfs merge=lfs -text
*.stl  filter=lfs diff=lfs merge=lfs -text
*.iges filter=lfs diff=lfs merge=lfs -text
*.igs  filter=lfs diff=lfs merge=lfs -text
*.f3d  filter=lfs diff=lfs merge=lfs -text
*.sldprt filter=lfs diff=lfs merge=lfs -text
*.sldasm filter=lfs diff=lfs merge=lfs -text
*.usd  filter=lfs diff=lfs merge=lfs -text
*.usda filter=lfs diff=lfs merge=lfs -text
*.usdc filter=lfs diff=lfs merge=lfs -text
```

Git LFSを使う場合は一度だけ実行する。

```bash
git lfs install
```

---

## 日常的な開発手順

### 1. VS Codeで編集

Ubuntu WSL側で実行する。

```bash
cd ~/OkiagariKoboshi_ws
code .
```

---

### 2. Isaac Labコンテナを起動

```bash
cd ~/OkiagariKoboshi_ws
docker compose --project-directory . -f docker/compose.isaaclab.yml up -d
```

---

### 3. コンテナに入る

```bash
docker compose --project-directory . -f docker/compose.isaaclab.yml exec isaaclab bash
```

---

### 4. コンテナ内で実行

```bash
cd /workspace/IsaacLab
./isaaclab.sh -p /workspace/OkiagariKoboshi_ws/isaac/scripts/check_env.py
```

---

### 5. コンテナから出る

```bash
exit
```

---

### 6. コンテナを止める

WSL側で実行する。

```bash
cd ~/OkiagariKoboshi_ws
docker compose --project-directory . -f docker/compose.isaaclab.yml down
```

---

## 開発の分担

Windows側では以下を行う。

```text
GitHub管理
VS Codeでコード編集
CAD整理
URDF / USD / mesh整理
M5Stack firmware作成
Isaac Lab用スクリプト作成
軽い動作確認
```

研究室Ubuntu / GPUサーバ側では以下を行う。

```text
NVIDIA Driver
Docker
NVIDIA Container Toolkit
Isaac Sim / Isaac Lab
PPO学習
大量並列シミュレーション
policy export
```

---

## policyの流れ

PC / GPUサーバ側：

```text
Isaac Lab
  ↓
PPO学習
  ↓
PyTorch policy
  ↓
小さいMLPへexport
  ↓
ONNX / C配列 / 手書き推論コード
```

M5Stack Core2側：

```text
IMU取得
  ↓
roll / pitch推定
  ↓
正規化 observation 作成
  ↓
policy推論
  ↓
目標サーボ角度
  ↓
2軸サーボへ送信
```

M5Stack Core2ではPyTorchを動かさない。
小さいMLPをC++で手書き推論する方針がよい。

例：

```text
入力:
  roll
  pitch
  roll_rate
  pitch_rate
  servo1_angle
  servo2_angle

出力:
  servo1_target
  servo2_target
```

小さいpolicy例：

```text
6入力
↓
Linear 16 + tanh
↓
Linear 16 + tanh
↓
Linear 2
```

---

## 現時点での到達状態

現時点でやったこと：

```text
OkiagariKoboshi_ws を作成
CADファイル用フォルダあり
Isaac Lab用 compose ファイルを配置
Docker Desktopで Ubuntu-24.04 WSL Integration をON
Isaac Labコンテナに入れる状態
コンテナ内で code . は使わないことを確認
WSL側とコンテナ側のマウント確認が必要
```

---

## 次にやること

1. `compose.isaaclab.yml` の `volumes:` を絶対パスに修正する
2. コンテナを `down` → `up -d --force-recreate` で作り直す
3. コンテナ内で作ったファイルがWSL側で見えるか確認する
4. VS CodeをWSL側で開く
5. `isaac/scripts/check_env.py` を作成する
6. Isaac LabのPython環境から実行する
7. GitHubにpushする

---

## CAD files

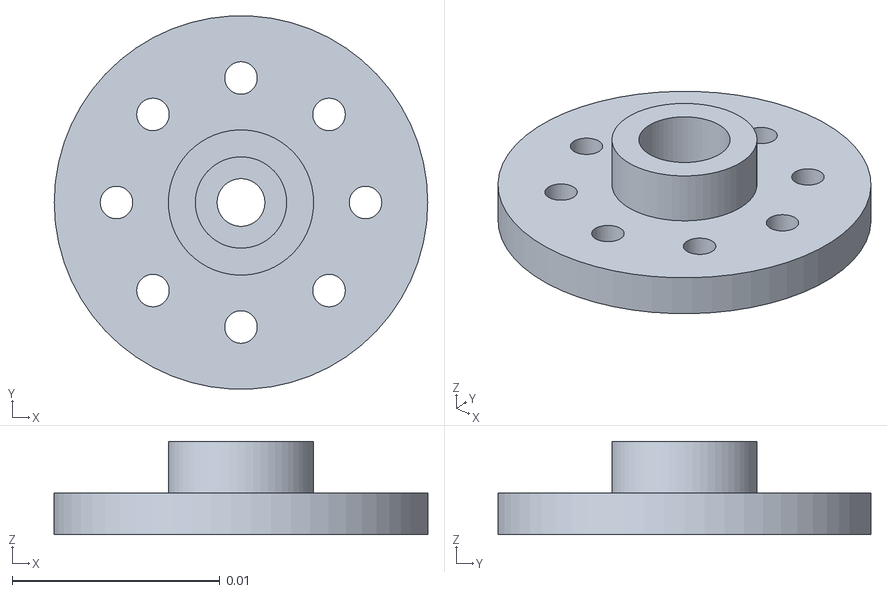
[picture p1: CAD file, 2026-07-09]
assets/meshes/STS3032_Horn.stl
0.018 x 0.018 x 0.0045

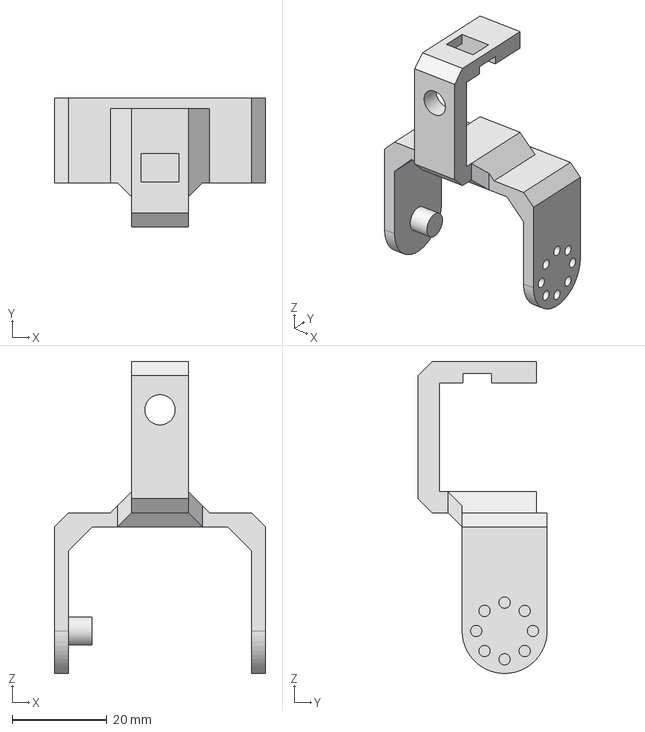
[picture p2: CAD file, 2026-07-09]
cad/Arm1.stp
44.7 x 27.4 x 66.0 mm

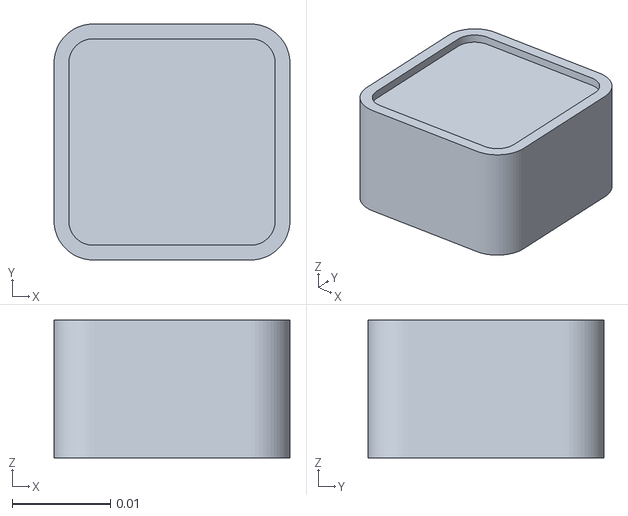
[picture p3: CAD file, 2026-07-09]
assets/meshes/M5Atom.stl
0.024 x 0.024 x 0.014

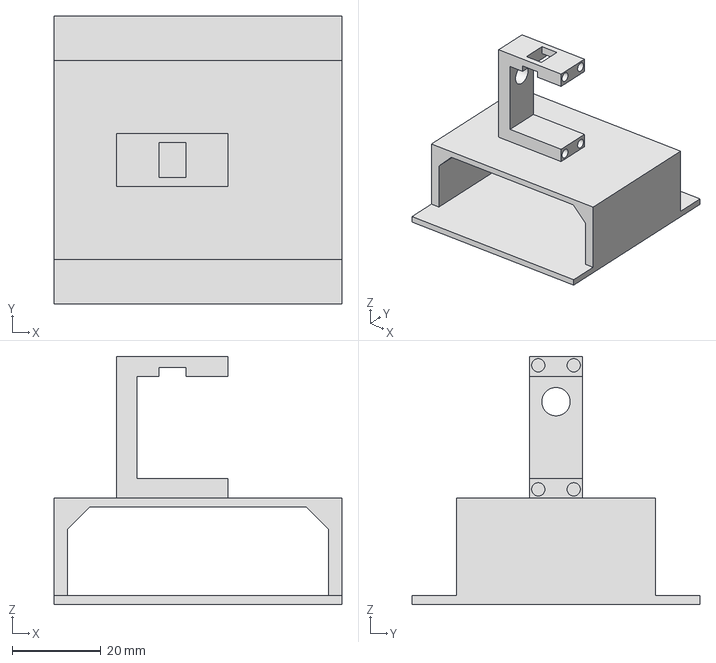
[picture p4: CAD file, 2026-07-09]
cad/Base.stp
65.0 x 65.0 x 56.0 mm

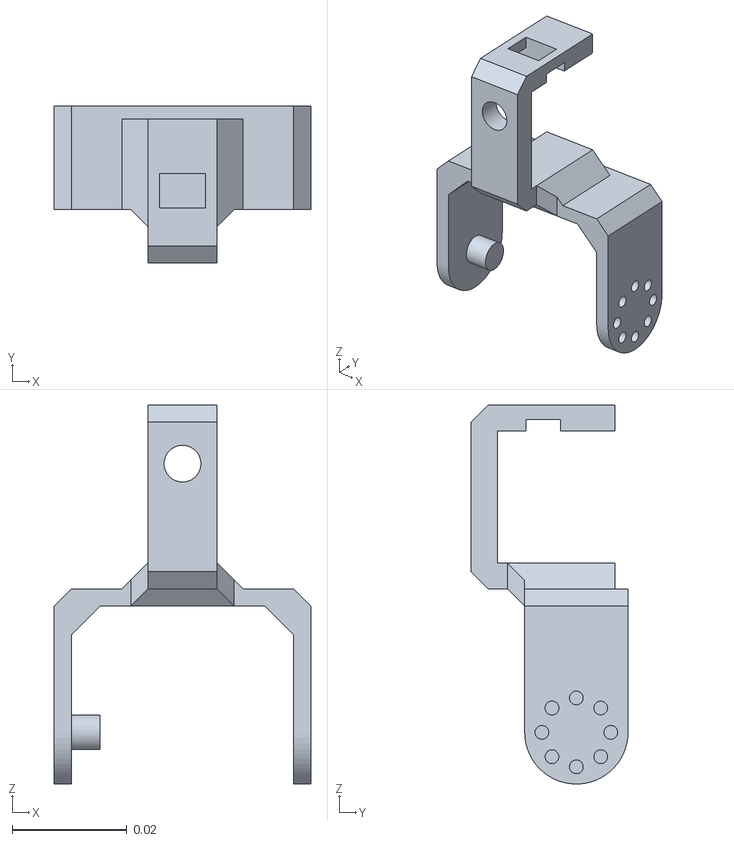
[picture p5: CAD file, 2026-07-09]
assets/meshes/Arm1.stl
0.0447 x 0.0273 x 0.066

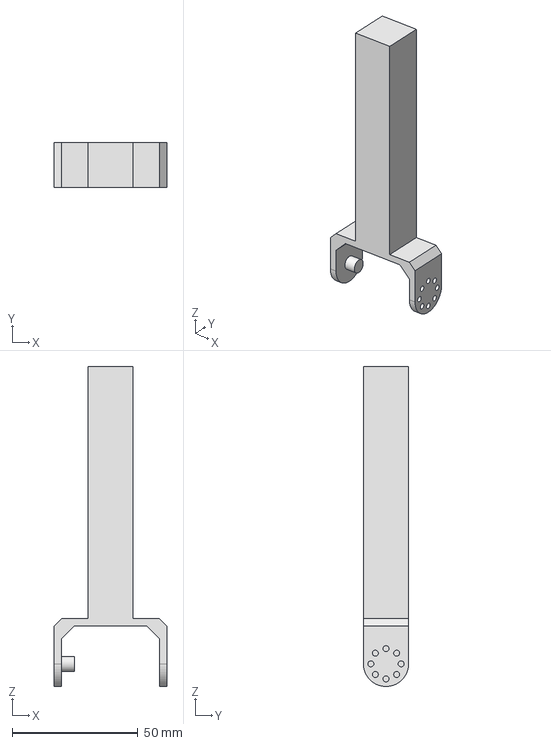
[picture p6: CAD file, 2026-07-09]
cad/Arm2.stp
44.7 x 18.0 x 127.0 mm

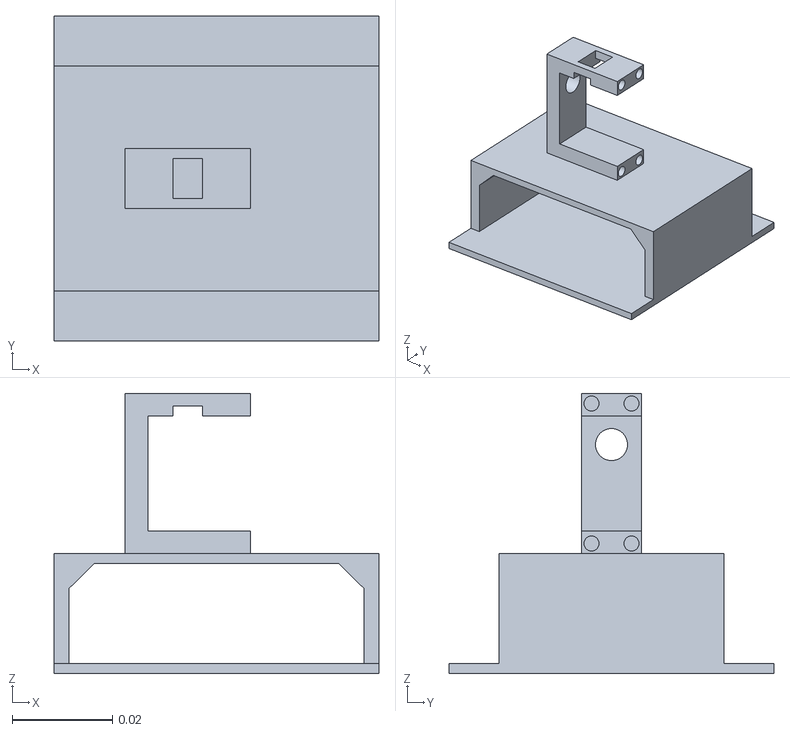
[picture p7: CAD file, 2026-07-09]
assets/meshes/Base.stl
0.065 x 0.065 x 0.056

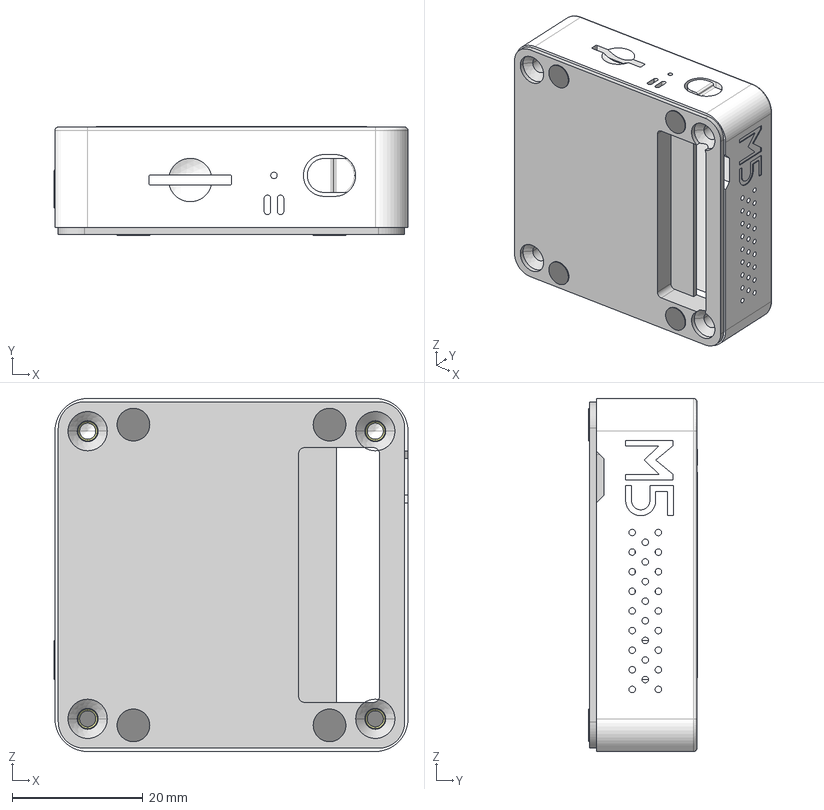
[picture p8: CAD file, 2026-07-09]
cad/M5Stack_Core2.stp
54.2 x 16.7 x 54.0 mm
M5Stack_Core2-prt0
M5Stack_Core2-prt1
M5Stack_Core2-prt2
M5Stack_Core2-prt3
M5Stack_Core2-prt4
M5Stack_Core2-prt5
M5Stack_Core2-prt6
M5Stack_Core2-prt7
M5Stack_Core2-prt8
M5Stack_Core2-prt9
M5Stack_Core2-prt10
M5Stack_Core2-prt11
M5Stack_Core2-prt12
M5Stack_Core2-prt13
M5Stack_Core2-prt14

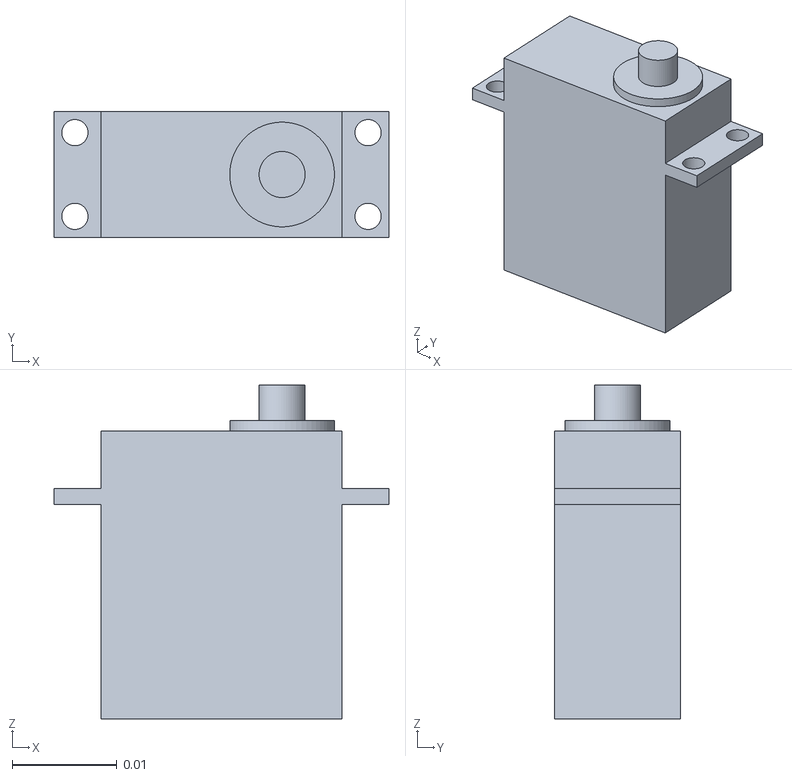
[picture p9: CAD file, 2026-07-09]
assets/meshes/STS3032.stl
0.032 x 0.012 x 0.0319

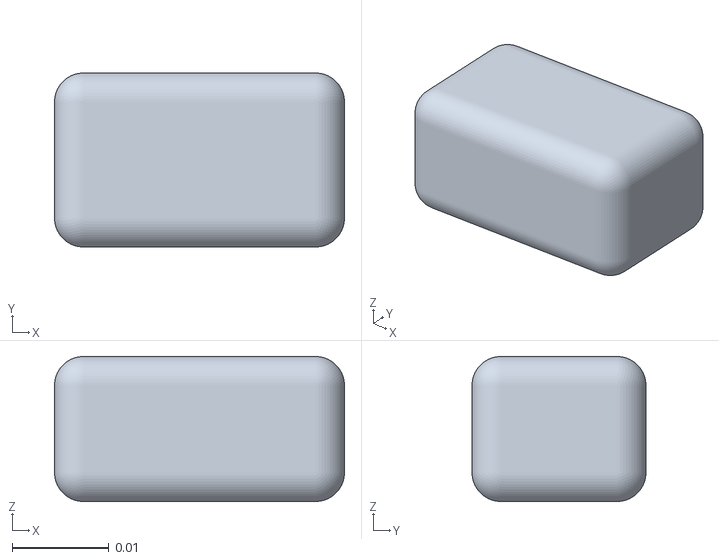
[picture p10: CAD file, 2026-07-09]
assets/meshes/Battery.stl
0.03 x 0.018 x 0.015

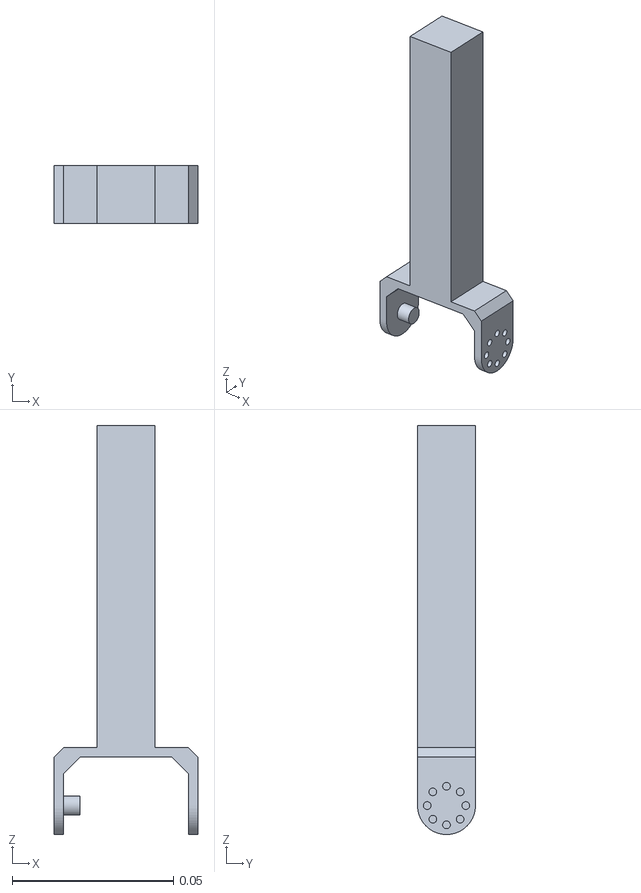
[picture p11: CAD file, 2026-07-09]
assets/meshes/Arm2.stl
0.0447 x 0.018 x 0.127

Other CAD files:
cad/Arm1.ipt
cad/Arm2.ipt
cad/Base.ipt
cad/Battery.ipt
cad/M5Atom.ipt
cad/M5Stack_Core2/M5Stack_Core2/M5Stack_Core2.ipt
cad/OkiagariKoboshi.iam
cad/OldVersions/Arm1.0011.ipt
cad/OldVersions/Arm1.0013.ipt
cad/OldVersions/Arm2.0005.ipt
cad/OldVersions/Base.0004.ipt
cad/OldVersions/Base.0010.ipt
cad/OldVersions/OkiagariKoboshi.0009.iam
cad/OldVersions/OkiagariKoboshi.0013.iam
cad/STS3032.ipt
cad/STS3032_Horn.ipt

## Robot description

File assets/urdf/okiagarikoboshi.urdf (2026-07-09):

<?xml version='1.0' encoding='utf-8'?>
<robot name="okiagarikoboshi">
    <link name="arm1">
        <inertial>
            <mass value="0.00677043" />
            <origin xyz="-0.0198303 -0.00332605 0.0238007" rpy="0 -0 0" />
            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
        </inertial>
        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
    </link>
    <link name="arm2">
        <inertial>
            <mass value="0.0168831" />
            <origin xyz="-0.0194738 -5.21533e-20 0.060118" rpy="0 -0 0" />
            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
        </inertial>
        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
    </link>
    <link name="base">
        <inertial>
            <mass value="0.034032" />
            <origin xyz="-0.00134323 3.38874e-18 0.0150396" rpy="0 -0 0" />
            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
        </inertial>
        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
    </link>
    <link name="battery">
        <inertial>
            <mass value="0.0095618" />
            <origin xyz="0 0.009 0.0075" rpy="0 -0 0" />
            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
        </inertial>
        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
    </link>
    <link name="m5atom">
        <inertial>
            <mass value="0.0092951" />
            <origin xyz="1.34715e-18 0 0.0066192" rpy="0 -0 0" />
            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
        </inertial>
        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
    </link>
    <link name="root" />
    <link name="sts3032">
        <inertial>
            <mass value="0.0212025" />
            <origin xyz="9.60267e-05 0.006 0.0141274" rpy="0 -0 0" />
            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
        </inertial>
        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
    </link>
    <link name="sts3032_1">
        <inertial>
            <mass value="0.0212025" />
            <origin xyz="9.60267e-05 -0.006 0.0141274" rpy="0 -0 0" />
            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
        </inertial>
        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
    </link>
    <link name="sts3032_horn">
        <inertial>
            <mass value="0.00140165" />
            <origin xyz="2.67641e-19 9.02511e-20 4.20229e-05" rpy="0 -0 0" />
            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
        </inertial>
        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
    </link>
    <link name="sts3032_horn_1">
        <inertial>
            <mass value="0.00140165" />
            <origin xyz="2.67641e-19 9.02511e-20 4.20229e-05" rpy="0 -0 0" />
            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
        </inertial>
        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
    </link>
    <joint name="fix1" type="fixed">
        <origin xyz="-0.01375 -0.006 0.04" rpy="0 -1.5708 3.14159" />
        <axis xyz="0 1 0" />
        <parent link="base" />
        <child link="sts3032_1" />
    </joint>
    <joint name="fix2" type="fixed">
        <origin xyz="4.33681e-19 0 -0.0012" rpy="0 1.5708 4.71239" />
        <axis xyz="-1 -0 -0" />
        <parent link="sts3032_horn_1" />
        <child link="arm1" />
    </joint>
    <joint name="fix3" type="fixed">
        <origin xyz="-0.02535 -0.01375 0.041" rpy="0 -1.5708 -1.5708" />
        <axis xyz="0 -1 0" />
        <parent link="arm1" />
        <child link="sts3032" />
    </joint>
    <joint name="fix4" type="fixed">
        <origin xyz="1.38778e-17 -1.51788e-17 -0.0012" rpy="0 1.5708 -4.24713e-15" />
        <axis xyz="-1 -0 -0" />
        <parent link="sts3032_horn" />
        <child link="arm2" />
    </joint>
    <joint name="fix5" type="fixed">
        <origin xyz="0.0295 0 0.002" rpy="0 -0 1.5708" />
        <axis xyz="-1 -2.22045e-16 -0" />
        <parent link="base" />
        <child link="battery" />
    </joint>
    <joint name="fix6" type="fixed">
        <origin xyz="-0.002 0.02 0.002" rpy="0 -0 0" />
        <axis xyz="0 0 -1" />
        <parent link="base" />
        <child link="m5atom" />
    </joint>
    <joint name="fixed_node_to_root_joint" type="fixed">
        <origin xyz="0.00169854 -0.00260265 -0.00443611" rpy="0 -0 0" />
        <axis xyz="0 0 1" />
        <parent link="root" />
        <child link="base" />
    </joint>
    <joint name="revolute1" type="revolute">
        <origin xyz="0.00579 -0.006 0.0319" rpy="3.14159 -4.44089e-16 -1.5708" />
        <axis xyz="0 0 -1" />
        <parent link="sts3032_1" />
        <child link="sts3032_horn_1" />
        <limit effort="1" velocity="1" lower="-1.5708" upper="1.5708" />
    </joint>
    <joint name="revolute2" type="revolute">
        <origin xyz="0.00579 0.006 0.0319" rpy="-3.14159 2.25509e-15 6.9571e-16" />
        <axis xyz="0 0 -1" />
        <parent link="sts3032" />
        <child link="sts3032_horn" />
        <limit effort="1" velocity="1" lower="-2.0944" upper="2.0944" />
    </joint>
</robot>

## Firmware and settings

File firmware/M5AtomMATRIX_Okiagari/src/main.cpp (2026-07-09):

#include <Arduino.h>
#include <M5Atom.h>
#include <SCServo.h>
#include <math.h>

#include "OkiagariPolicy.h"

namespace {

constexpr uint32_t kDefaultServoBaud = 1000000;
constexpr int8_t kDefaultServoRxPin = 32;
constexpr int8_t kDefaultServoTxPin = 26;
constexpr uint32_t kServoBaudRates[] = {
    1000000, 500000, 250000, 128000, 115200, 76800,
    57600,   38400,  19200,  14400,  9600,   4800,
};

constexpr uint8_t kServoCount = 2;
uint8_t kServoIds[kServoCount] = {1, 2};

constexpr uint16_t kServoSpeed = 1200;
constexpr uint8_t kServoAcc = 150;
constexpr uint16_t kServoTorque = 800;

constexpr float kPolicyHz = 50.0f;
constexpr uint32_t kPolicyPeriodMs = static_cast<uint32_t>(1000.0f / kPolicyHz);
constexpr float kPolicyDt = 1.0f / kPolicyHz;

constexpr float kEpisodeLengthS = 4.0f;
constexpr float kDropSettleTimeS = 0.35f;
constexpr float kReferenceEndTimeS = 3.50f;

constexpr float kActionScale1Rad = 1.20f;
constexpr float kActionScale2Rad = 1.50f;
constexpr float kJoint1LimitRad = 1.57f;
constexpr float kJoint2LimitRad = 2.09f;
constexpr float kGyroScale = 0.25f;
constexpr float kJointVelScale = 0.10f;
constexpr float kServoSpeedLimitRadS = 1.0471976f / 0.09f;
constexpr float kAutoStartTiltRad = 0.75f;
constexpr float kImuAccSignX = 1.0f;
constexpr float kImuAccSignY = -1.0f;
constexpr float kImuAccSignZ = -1.0f;
constexpr float kImuGyroSignX = 1.0f;
constexpr float kImuGyroSignY = -1.0f;

constexpr int16_t kServoMinTicks = 0;
constexpr int16_t kServoMaxTicks = 4095;
constexpr int16_t kServoCenterTicks[kServoCount] = {2047, 2047};
constexpr float kServoSign[kServoCount] = {1.0f, 1.0f};
constexpr float kServoTicksPerRad[kServoCount] = {
    4095.0f / (2.0f * PI),
    4095.0f / (2.0f * PI),
};

struct ReferencePoint {
    float t;
    float q1;
    float q2;
};

constexpr ReferencePoint kReferenceRollPos[] = {
    {1.00f, 0.00f, 0.00f},
    {1.50f, -1.57f, 0.00f},
    {3.00f, -1.57f, 0.00f},
    {3.50f, 0.00f, 0.00f},
};

constexpr ReferencePoint kReferenceRollNeg[] = {
    {1.00f, 0.00f, 0.00f},
    {1.50f, 1.57f, 0.00f},
    {3.00f, 1.57f, 0.00f},
    {3.50f, 0.00f, 0.00f},
};

constexpr ReferencePoint kReferencePitchPos[] = {
    {1.00f, 0.00f, 0.00f},
    {1.50f, 0.00f, -2.09f},
    {3.00f, 0.00f, -2.09f},
    {3.50f, 0.00f, 0.00f},
};

constexpr ReferencePoint kReferencePitchNeg[] = {
    {1.00f, 0.00f, 0.00f},
    {1.50f, 0.00f, 2.09f},
    {3.00f, 0.00f, 2.09f},
    {3.50f, 0.00f, 0.00f},
};

enum class RunMode : uint8_t {
    Reference,
    Policy,
};

enum class ReferenceMode : uint8_t {
    Auto,
    RollPos,
    RollNeg,
    PitchPos,
    PitchNeg,
};

HLSCL servoBus;

RunMode runMode = RunMode::Policy;
ReferenceMode selectedReference = ReferenceMode::Auto;
ReferenceMode activeReference = ReferenceMode::RollPos;

uint8_t servoBaudIndex = 0;
uint32_t servoBaud = kDefaultServoBaud;
int8_t servoRxPin = kDefaultServoRxPin;
int8_t servoTxPin = kDefaultServoTxPin;

bool controllerEnabled = false;
bool policyAvailable = false;
bool autoStartOnTilt = true;
bool verboseServoLog = true;
uint32_t nextPolicyMs = 0;
uint32_t episodeStartMs = 0;
uint32_t lastLedMs = 0;
uint32_t lastDebugMs = 0;
uint32_t lastServoWriteDebugMs = 0;
uint32_t lastIdleImuDebugMs = 0;
float lastRollRad = 0.0f;
float lastPitchRad = 0.0f;

float jointPosRad[kServoCount] = {0.0f, 0.0f};
float jointVelRadS[kServoCount] = {0.0f, 0.0f};
float servoTargetRad[kServoCount] = {0.0f, 0.0f};

float clampFloat(float value, float low, float high) {
    if (value < low) return low;
    if (value > high) return high;
    return value;
}

int16_t clampTicks(int32_t ticks) {
    if (ticks < kServoMinTicks) return kServoMinTicks;
    if (ticks > kServoMaxTicks) return kServoMaxTicks;
    return ticks;
}

float ticksToRad(uint8_t index, int ticks) {
    return (static_cast<float>(ticks) - kServoCenterTicks[index]) /
           (kServoSign[index] * kServoTicksPerRad[index]);
}

int16_t radToTicks(uint8_t index, float radians) {
    const float raw = kServoCenterTicks[index] +
                      kServoSign[index] * radians * kServoTicksPerRad[index];
    return clampTicks(lroundf(raw));
}

const char* referenceName(ReferenceMode mode) {
    switch (mode) {
        case ReferenceMode::RollPos:
            return "roll_pos";
        case ReferenceMode::RollNeg:
            return "roll_neg";
        case ReferenceMode::PitchPos:
            return "pitch_pos";
        case ReferenceMode::PitchNeg:
            return "pitch_neg";
        case ReferenceMode::Auto:
        default:
            return "auto";
    }
}

const char* servoErrorName(uint8_t err) {
    switch (err) {
        case 0:
            return "OK";
        case ERR_NO_REPLY:
            return "NO_REPLY";
        case ERR_CRC_CMP:
            return "CRC";
        case ERR_SLAVE_ID:
            return "SLAVE_ID";
        case ERR_BUFF_LEN:
            return "BUFF_LEN";
        default:
            return "UNKNOWN";
    }
}

void printServoResult(const char* op, uint8_t id, int result) {
    const uint8_t err = servoBus.getLastError();
    Serial.printf("[servo] %s id=%u result=%d err=%u(%s) state=%u\n", op, id,
                  result, err, servoErrorName(err), servoBus.getState());
}

void beginServoUart() {
    Serial2.end();
    delay(20);
    Serial2.begin(servoBaud, SERIAL_8N1, servoRxPin, servoTxPin);
    servoBus.pSerial = &Serial2;
    servoBus.IOTimeOut = 30;
    delay(100);

    Serial.printf("[servo] uart begin Serial2 baud=%lu rx=%d tx=%d timeout=%lu\n",
                  static_cast<unsigned long>(servoBaud), servoRxPin,
                  servoTxPin, servoBus.IOTimeOut);
}

void cycleServoBaud() {
    servoBaudIndex =
        (servoBaudIndex + 1) %
        (sizeof(kServoBaudRates) / sizeof(kServoBaudRates[0]));
    servoBaud = kServoBaudRates[servoBaudIndex];
    beginServoUart();
}

void swapServoPins() {
    const int8_t oldRx = servoRxPin;
    servoRxPin = servoTxPin;
    servoTxPin = oldRx;
    beginServoUart();
}

void setStatusColor(const CRGB& color) {
    M5.dis.fillpix(color);
}

void updateStatusLed() {
    const uint32_t now = millis();
    if (now - lastLedMs < 200) return;
    lastLedMs = now;

    if (!controllerEnabled) {
        setStatusColor(CRGB(0, 0, 24));
    } else if (!policyAvailable) {
        setStatusColor(CRGB(24, 16, 0));
    } else {
        setStatusColor(CRGB(0, 24, 0));
    }
}

void writeServoTargets() {
    s16 positions[kServoCount];
    u16 speeds[kServoCount];
    u8 accs[kServoCount];
    u16 torques[kServoCount];

    for (uint8_t i = 0; i < kServoCount; ++i) {
        positions[i] = radToTicks(i, servoTargetRad[i]);
        speeds[i] = kServoSpeed;
        accs[i] = kServoAcc;
        torques[i] = kServoTorque;
    }

    servoBus.SyncWritePosEx(kServoIds, kServoCount, positions, speeds, accs,
                            torques);

    const uint32_t now = millis();
    if (verboseServoLog && now - lastServoWriteDebugMs >= 200) {
        lastServoWriteDebugMs = now;
        Serial.printf(
            "[servo] syncWrite pos=%d,%d target_rad=%.3f,%.3f speed=%u acc=%u torque=%u\n",
            positions[0], positions[1], servoTargetRad[0], servoTargetRad[1],
            kServoSpeed, kServoAcc, kServoTorque);
    }
}

void moveTargetsToward(const float desired[kServoCount]) {
    const float maxDelta = kServoSpeedLimitRadS * kPolicyDt;
    for (uint8_t i = 0; i < kServoCount; ++i) {
        const float delta = clampFloat(desired[i] - servoTargetRad[i],
                                       -maxDelta, maxDelta);
        servoTargetRad[i] += delta;
    }
}

void readServoState() {
    static float prevPosRad[kServoCount] = {0.0f, 0.0f};

    for (uint8_t i = 0; i < kServoCount; ++i) {
        const int posTicks = servoBus.ReadPos(kServoIds[i]);
        if (posTicks >= kServoMinTicks && posTicks <= kServoMaxTicks) {
            jointPosRad[i] = ticksToRad(i, posTicks);
        }

        const int speedTicks = servoBus.ReadSpeed(kServoIds[i]);
        if (speedTicks >= -32768 && speedTicks <= 32767) {
            jointVelRadS[i] = (jointPosRad[i] - prevPosRad[i]) / kPolicyDt;
        } else {
            jointVelRadS[i] = 0.0f;
        }
        prevPosRad[i] = jointPosRad[i];
    }
}

void printServoSnapshot() {
    Serial.println("[servo] snapshot begin");
    for (uint8_t i = 0; i < kServoCount; ++i) {
        const uint8_t id = kServoIds[i];
        const int ping = servoBus.Ping(id);
        const uint8_t pingErr = servoBus.getLastError();
        const int mode = servoBus.readByte(id, HLSCL_MODE);
        const uint8_t modeErr = servoBus.getLastError();
        const int torqueEnable = servoBus.readByte(id, HLSCL_TORQUE_ENABLE);
        const uint8_t torqueErr = servoBus.getLastError();
        const int pos = servoBus.ReadPos(id);
        const uint8_t posErr = servoBus.getLastError();
        const int speed = servoBus.ReadSpeed(id);
        const uint8_t speedErr = servoBus.getLastError();
        const int voltage = servoBus.ReadVoltage(id);
        const uint8_t voltageErr = servoBus.getLastError();
        const int temp = servoBus.ReadTemper(id);
        const uint8_t tempErr = servoBus.getLastError();

        Serial.printf(
            "[servo] id=%u ping=%d(err=%u:%s) mode=%d(err=%u:%s) torque=%d(err=%u:%s) pos=%d(err=%u:%s) speed=%d(err=%u:%s) voltage=%d(err=%u:%s) temp=%d(err=%u:%s)\n",
            id, ping, pingErr, servoErrorName(pingErr), mode, modeErr,
            servoErrorName(modeErr), torqueEnable, torqueErr,
            servoErrorName(torqueErr), pos, posErr, servoErrorName(posErr),
            speed, speedErr, servoErrorName(speedErr), voltage, voltageErr,
            servoErrorName(voltageErr), temp, tempErr, servoErrorName(tempErr));
    }
    Serial.println("[servo] snapshot end");
}

void writeIndividualTargetTicks(int16_t offsetTicks) {
    Serial.printf("[servo] individual WritePosEx offset=%d\n", offsetTicks);
    for (uint8_t i = 0; i < kServoCount; ++i) {
        const int16_t position =
            clampTicks(static_cast<int32_t>(kServoCenterTicks[i]) + offsetTicks);
        servoTargetRad[i] = ticksToRad(i, position);
        const int result = servoBus.WritePosEx(kServoIds[i], position,
                                               kServoSpeed, kServoAcc,
                                               kServoTorque);
        Serial.printf("[servo] write id=%u pos=%d rad=%.3f\n", kServoIds[i],
                      position, servoTargetRad[i]);
        printServoResult("WritePosEx", kServoIds[i], result);
    }
}

void runServoDiagnostics() {
    Serial.printf("[servo] uart=Serial2 baud=%lu rx=%d tx=%d timeout=%lu ids=%u,%u center=%d,%d\n",
                  static_cast<unsigned long>(servoBaud), servoRxPin,
                  servoTxPin, servoBus.IOTimeOut, kServoIds[0], kServoIds[1],
                  kServoCenterTicks[0], kServoCenterTicks[1]);

    for (uint8_t i = 0; i < kServoCount; ++i) {
        const uint8_t id = kServoIds[i];
        printServoResult("Ping", id, servoBus.Ping(id));
        printServoResult("ServoMode", id, servoBus.ServoMode(id));
        printServoResult("EnableTorque", id, servoBus.EnableTorque(id, 1));
    }

    printServoSnapshot();
}

void scanServoIds() {
    Serial.printf("[servo] scan ids 0..10 baud=%lu rx=%d tx=%d\n",
                  static_cast<unsigned long>(servoBaud), servoRxPin,
                  servoTxPin);
    for (uint8_t id = 0; id <= 10; ++id) {
        const int ping = servoBus.Ping(id);
        const uint8_t err = servoBus.getLastError();
        Serial.printf("[servo] scan id=%u ping=%d err=%u(%s)\n", id, ping, err,
                      servoErrorName(err));
        delay(20);
    }
}

void readImuAttitude(float& roll, float& pitch, float& gyroXRadS,
                     float& gyroYRadS) {
    float accX = 0.0f;
    float accY = 0.0f;
    float accZ = 1.0f;
    float gyroXDps = 0.0f;
    float gyroYDps = 0.0f;
    float gyroZDps = 0.0f;

    M5.IMU.getAccelData(&accX, &accY, &accZ);
    M5.IMU.getGyroData(&gyroXDps, &gyroYDps, &gyroZDps);
    (void)gyroZDps;

    accX *= kImuAccSignX;
    accY *= kImuAccSignY;
    accZ *= kImuAccSignZ;
    gyroXDps *= kImuGyroSignX;
    gyroYDps *= kImuGyroSignY;

    pitch = asinf(clampFloat(-accX, -1.0f, 1.0f));
    roll = atan2f(accY, accZ);
    gyroXRadS = gyroXDps * DEG_TO_RAD;
    gyroYRadS = gyroYDps * DEG_TO_RAD;
    lastRollRad = roll;
    lastPitchRad = pitch;
}

ReferenceMode detectReferenceMode() {
    float roll = 0.0f;
    float pitch = 0.0f;
    float gyroXRadS = 0.0f;
    float gyroYRadS = 0.0f;
    readImuAttitude(roll, pitch, gyroXRadS, gyroYRadS);

    if (fabsf(roll) >= fabsf(pitch)) {
        return roll >= 0.0f ? ReferenceMode::RollPos : ReferenceMode::RollNeg;
    }
    return pitch >= 0.0f ? ReferenceMode::PitchPos : ReferenceMode::PitchNeg;
}

float taskTimeSeconds() {
    if (!controllerEnabled) return 0.0f;
    return 0.001f * static_cast<float>(millis() - episodeStartMs);
}

void buildObservation(float obs[OkiagariPolicy::kObservationSize]) {
    float roll = 0.0f;
    float pitch = 0.0f;
    float gyroXRadS = 0.0f;
    float gyroYRadS = 0.0f;
    readImuAttitude(roll, pitch, gyroXRadS, gyroYRadS);

    const float taskTime = max(0.0f, taskTimeSeconds() - kDropSettleTimeS);
    const float taskLength = max(kEpisodeLengthS - kDropSettleTimeS, 1.0e-6f);
    const float episodePhase = clampFloat(taskTime / taskLength, 0.0f, 1.0f);

    // Must match okiagari_getup_env.py::_get_observations().
    obs[0] = sinf(roll);
    obs[1] = cosf(roll);
    obs[2] = sinf(pitch);
    obs[3] = cosf(pitch);
    obs[4] = gyroXRadS * kGyroScale;
    obs[5] = gyroYRadS * kGyroScale;
    obs[6] = clampFloat(jointPosRad[0] / kActionScale1Rad, -1.5f, 1.5f);
    obs[7] = clampFloat(jointPosRad[1] / kActionScale2Rad, -1.5f, 1.5f);
    obs[8] = jointVelRadS[0] * kJointVelScale;
    obs[9] = jointVelRadS[1] * kJointVelScale;
    obs[10] = servoTargetRad[0] / kJoint1LimitRad;
    obs[11] = servoTargetRad[1] / kJoint2LimitRad;
    obs[12] = episodePhase;
}

void referenceTarget(ReferenceMode mode, float taskTime, float target[kServoCount]) {
    const ReferencePoint* ref = kReferenceRollPos;
    size_t count = sizeof(kReferenceRollPos) / sizeof(kReferenceRollPos[0]);

    switch (mode) {
        case ReferenceMode::RollNeg:
            ref = kReferenceRollNeg;
            count = sizeof(kReferenceRollNeg) / sizeof(kReferenceRollNeg[0]);
            break;
        case ReferenceMode::PitchPos:
            ref = kReferencePitchPos;
            count = sizeof(kReferencePitchPos) / sizeof(kReferencePitchPos[0]);
            break;
        case ReferenceMode::PitchNeg:
            ref = kReferencePitchNeg;
            count = sizeof(kReferencePitchNeg) / sizeof(kReferencePitchNeg[0]);
            break;
        case ReferenceMode::RollPos:
        case ReferenceMode::Auto:
        default:
            break;
    }

    target[0] = 0.0f;
    target[1] = 0.0f;

    if (taskTime < ref[0].t) return;

    for (size_t i = 0; i + 1 < count; ++i) {
        if (taskTime >= ref[i].t && taskTime < ref[i + 1].t) {
            const float alpha =
                clampFloat((taskTime - ref[i].t) / (ref[i + 1].t - ref[i].t),
                           0.0f, 1.0f);
            target[0] = ref[i].q1 + (ref[i + 1].q1 - ref[i].q1) * alpha;
            target[1] = ref[i].q2 + (ref[i + 1].q2 - ref[i].q2) * alpha;
            return;
        }
    }

    target[0] = ref[count - 1].q1;
    target[1] = ref[count - 1].q2;
}

void sanitizeAction(float action[OkiagariPolicy::kActionSize]) {
    for (size_t i = 0; i < OkiagariPolicy::kActionSize; ++i) {
        if (!isfinite(action[i])) action[i] = 0.0f;
        action[i] = clampFloat(action[i], -1.0f, 1.0f);
    }
}

void runPolicyStep() {
    readServoState();

    float obs[OkiagariPolicy::kObservationSize];
    float action[OkiagariPolicy::kActionSize] = {0.0f, 0.0f};
    buildObservation(obs);

    float desiredRad[kServoCount] = {0.0f, 0.0f};
    const float elapsed = taskTimeSeconds();
    const float taskTime = max(0.0f, elapsed - kDropSettleTimeS);

    if (runMode == RunMode::Reference) {
        policyAvailable = true;
        if (controllerEnabled && elapsed >= kDropSettleTimeS) {
            referenceTarget(activeReference, taskTime, desiredRad);
        }
    } else {
        policyAvailable = OkiagariPolicy::run(obs, action);
        sanitizeAction(action);
    }

    if (runMode == RunMode::Policy && controllerEnabled && policyAvailable &&
        elapsed >= kDropSettleTimeS) {
        desiredRad[0] = action[0] * kJoint1LimitRad;
        desiredRad[1] = action[1] * kJoint2LimitRad;
    }

    moveTargetsToward(desiredRad);
    writeServoTargets();

    const uint32_t now = millis();
    if (now - lastDebugMs >= 100) {
        lastDebugMs = now;
        Serial.printf(
            "enabled=%d mode=%s ref=%s elapsed=%.3f task=%.3f phase=%.3f roll=%.3f pitch=%.3f obs0=%.3f obs2=%.3f action=%.3f,%.3f desired=%.3f,%.3f target=%.3f,%.3f joint=%.3f,%.3f\n",
            controllerEnabled ? 1 : 0,
            runMode == RunMode::Reference ? "reference" : "policy",
            referenceName(activeReference), elapsed, taskTime, obs[12],
            lastRollRad, lastPitchRad, obs[0], obs[2], action[0], action[1],
            desiredRad[0], desiredRad[1], servoTargetRad[0],
            servoTargetRad[1], jointPosRad[0], jointPosRad[1]);
    }
}

bool referenceFinished() {
    return runMode == RunMode::Reference && controllerEnabled &&
           taskTimeSeconds() - kDropSettleTimeS > kReferenceEndTimeS + 0.1f;
}

void startController() {
    if (runMode == RunMode::Reference) {
        activeReference = selectedReference == ReferenceMode::Auto
                              ? detectReferenceMode()
                              : selectedReference;
    }
    controllerEnabled = true;
    episodeStartMs = millis();
    nextPolicyMs = millis();
    servoTargetRad[0] = 0.0f;
    servoTargetRad[1] = 0.0f;
    Serial.printf("controller enabled, mode=%s, reference=%s\n",
                  runMode == RunMode::Reference ? "reference" : "policy",
                  referenceName(activeReference));
}

void handleIdleTiltTrigger() {
    float roll = 0.0f;
    float pitch = 0.0f;
    float gyroXRadS = 0.0f;
    float gyroYRadS = 0.0f;
    readImuAttitude(roll, pitch, gyroXRadS, gyroYRadS);
    const float tilt = max(fabsf(roll), fabsf(pitch));

    const uint32_t now = millis();
    if (now - lastIdleImuDebugMs >= 500) {
        lastIdleImuDebugMs = now;
        Serial.printf(
            "[imu] idle roll=%.3f pitch=%.3f tilt=%.3f threshold=%.3f auto=%d\n",
            roll, pitch, tilt, kAutoStartTiltRad, autoStartOnTilt ? 1 : 0);
    }

    if (autoStartOnTilt && tilt >= kAutoStartTiltRad) {
        Serial.printf("[imu] tilt trigger roll=%.3f pitch=%.3f tilt=%.3f\n",
                      roll, pitch, tilt);
        startController();
    }
}

void stopController() {
    controllerEnabled = false;
    servoTargetRad[0] = 0.0f;
    servoTargetRad[1] = 0.0f;
    writeServoTargets();
    Serial.println("controller disabled");
}
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
void loop() {
    handleInputs();
    updateStatusLed();

    if (!controllerEnabled) {
        handleIdleTiltTrigger();
        delay(2);
        return;
    }

    const uint32_t now = millis();
    if (static_cast<int32_t>(now - nextPolicyMs) >= 0) {
        nextPolicyMs += kPolicyPeriodMs;
        runPolicyStep();
        if (referenceFinished()) {
            Serial.println("[ref] finished; stopping to allow next tilt re-detect");
            stopController();
        }
    }

    delay(1);
}

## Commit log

2026-07-09 M5ファームウェア追加
2026-07-09 READMEの追加
